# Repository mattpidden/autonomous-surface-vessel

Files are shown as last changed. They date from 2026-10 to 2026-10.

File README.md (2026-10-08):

# Autonomous Surface Vessel (ASV) Project
A 3D-printed autonomous sailing surface vessel designed for marine data collection and experimentation in autonomous navigation. 

## Capabilities
- Autonomous waypoint navigation
- Sail and rudder control
- GPS based localisation
- IMU-based heading and motion estimation
- Wind-aware sailing and route planning
- Marine environmental data collection
- Georeferenced data logging
- Computer vision for surface obstacle detection
- Remote telemetry and mission monitoring
- Autonomous mission planning

## Parts

### Compute & control (£135.00)
- [x] [Raspberry Pi 4 4GB](https://thepihut.com/products/raspberry-pi-4-model-b?variant=20064052740158) | ✓ £96.00 | 4GB is plenty for headless ROS 2 + light vision. 
- [x] [SanDisk High Endurance 64GB microSD](https://www.amazon.co.uk/SanDisk-Endurance-Monitoring-Dashcams-MicroSDXC/dp/B07P3D6Y5B) | £24 | Made for continuous writing, so it suits all-day data logging.
- [x] [Pico](https://thepihut.com/products/pimoroni-pico-lipo-2) | ✓ £15.00 | Pimoroni Pico LiPo 2 (RP2350). USB-C, Qw/ST and SP/CE connectors.

### Navigation & comms (£88.60)
- [x] [Waveshare A7670E Cat-1](https://thepihut.com/products/a7670e-lte-cat-1-hat-for-raspberry-pi-2g-gsm-gprs) | ✓ £28.80 | LTE telemetry.
- [x] [IoT data SIM](TODO) | ~£10 | Low-data telemetry SIM.
- [x] [Adafruit BNO055 9-DoF IMU](https://thepihut.com/products/adafruit-9-dof-absolute-orientation-imu-fusion-breakout-bno055-stemma-qt-qwiic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) | ✓ £28.80 | Does sensor fusion on the chip and gives roll, pitch and turn rate
- [x] [STEMMA QT Cable x2](https://thepihut.com/products/stemma-qt-qwiic-jst-sh-4-pin-cable-100mm-long) | ✓ £2.00
- [x] [USB-C to USB-A cables x2](https://thepihut.com/products/usb-a-to-usb-c-cable-1m) for LTE hat and for Pi to Pico | ✓ £7.00
- [x] [USB GPS](https://www.amazon.co.uk/Receiver-Navigation-Notebook-Interface-DC3-3-5V/dp/B0BRQGZ4QV) | £14

### Vision (£39.60)
- [x] [Raspberry Pi Camera Module 3 Wide](https://thepihut.com/products/raspberry-pi-camera-module-3) | ✓ £33.60 | CSI, 120° view, autofocus, HDR. Uses less power than USB and works with the ROS 2 `camera_ros` package.
- [ ] [Clear Protectino Dome for camera](TODO) | ~£6
- [x] [Longer camera cable](https://thepihut.com/products/flex-cable-for-raspberry-pi-camera-or-display-18-457mm)

### Environmental sensors (£123.20)
- [x] [Pressure Humidity Temperature PHT Sensor](https://thepihut.com/products/adafruit-ms8607-pressure-humidity-temperature-pht-sensor) | ✓ £14.40 | Air temp/humidity/pressure. Mount it on deck in a vented, shaded housing. Can be dasiy changed into IMU sensor.
- [x] [Wind Speed & Direction Transmiter](https://www.amazon.co.uk/Ultrasonic-Direction-Sensor-Anemometer-Measurable/dp/B0H3613T5G) | £83
- [x] [RS485 to TTL adapter](https://www.amazon.co.uk/Converter-Direction-Compatible-Industrial-Automation/dp/B0GVQRYVNQ) | £5.4 | Check it supports 3.3V logic.
- [x] [TTL to 8pin cable](https://thepihut.com/products/8-pin-jst-sh-cable-sp-ce?variant=53798448431489) | ✓ £1.80 | Pick the JST-SH to DuPont version.

### Actuation (£102.40)
- [x] [12V Worm Gear Motor with Encoders x2](https://www.amazon.co.uk/Torque-Geared-Reduction-Encoder-Self-locking/dp/B07DG9QYPY) 30RPM for rudder and 10RPM for wing sail | £27 (£13.8 each)
- [x] [Motor driver](https://thepihut.com/products/dc-motor-driver-module-for-raspberry-pi-pico) | ✓ £14.40
- [x] [Power adapter for driver](https://thepihut.com/products/dc-dc-power-module-25w) £8.20
- [x] [Thruster motor](https://www.amazon.co.uk/ApisQueen-U2-Bi-Directional-ESC-Screw-Propellers/dp/B0C74CMXR9) | £62

### Power (£92.00)
- [x] [12V 12Ah LiFePO4 battery](https://www.amazon.co.uk/DCHOUSE-Trolling-Household-Appliances-Emergency/dp/B0CNP6Q28P) | £41.5 | 
- [x] [Battery Charger](https://www.amazon.co.uk/ECO-WORTHY-Lithium-LiFePO4-Automatic-Maintainer-black/dp/B0DGL4HKS6?th=1) | 36gbp
- [x] [Step down 12V to 5V for Pi](https://www.amazon.co.uk/DC-DC-Step-Converter-Type-C-Interface-as-shown-detailed-picture/dp/B0H7S63FXC) | £9
- [x] [On/off switch](https://www.amazon.co.uk/Joinfworld-Waterproof-Toggle-Mounting-Automotive/dp/B0G3982R8M) 10gbp

### Structure (£18.00)
- [ ] [Keel weights (lead)](https://www.claygame.co.uk/lead-shot-samples-pd378) | £18 for 2kg
- [ ] [2KG ABA Filament](https://uk.store.bambulab.com/products/abs-filament?id=41905581916220) £30

## Power budget (average draw at the battery)
| Load | Watts |
|---|---|
| Pi 4 headless + ROS 2 (after ~90% efficient 5V converter) | 3.5 |
| Camera + low-rate obstacle detection (runs part of the time) | 0.8 |
| Ultrasonic wind sensor (12V) | 0.6 |
| LTE Cat-1 telemetry | 0.5 |
| Rudder worm gear (self-locking, moves often) | 0.5 |
| Pico LiPo 2 | 0.15 |
| USB GPS | 0.15 |
| Sail worm gear (self-locking, moves rarely) | 0.15 |
| IMU, PHT sensor, motor driver idle | 0.1 |
| **Total** | **~6.5 W, ~155 Wh/day** |

A 12Ah LiFePO4 holds ~154Wh (~138Wh usable), which gives **~21h with no thruster use**. The thruster draws tens of watts, so every hour it runs costs several hours of endurance. To reach 24h, run the camera only near obstacles or in harbours, turn off Wi-Fi/Bluetooth/HDMI, or fit a larger battery if the weight budget allows. The wind sensor figure is typical for ultrasonic sensors, so check its datasheet.

## Software stack
**Raspberry Pi 4** (Ubuntu Server 24.04, headless, ROS 2 Jazzy)
- Localisation: `robot_localization` EKF fusing USB GPS (`nmea_navsat_driver`) with IMU heading from the Pico
- Planning: wind-aware sailing planner that turns waypoints into a course to steer and decides when to tack
- Vision: `camera_ros` + lightweight obstacle detection at a low frame rate
- Telemetry over LTE, and data logging with `rosbag2`

**Pimoroni Pico LiPo 2** (micro-ROS over USB serial, or a simple serial bridge if micro-ROS doesn't support the RP2350 yet)
- Reads the IMU and PHT sensor over I2C (Qw/ST) and the wind sensor over RS485/Modbus (SP/CE)
- Drives the rudder and sail worm gears to position using their encoders. Both are centred by hand at startup.
- Steers to the course from the Pi and trims the sail to the wind
- Sends the thruster ESC its PWM signal

## Assembly
- 3D print the hull in 3x1 sections with conectors
- Use acertone to bond together, then coat in epoxy
- Same for keel, which bolts into hull from inside
- Same for wing sail
- Use heat sets into the hull for modular plate system
- Design modular plate system to house all electronics
- Grease stuffed tubes for rudder and sail shafts
- Pole bolted to transom for Wind sensor, celluar arial, and IMU/PHT mounting 
- Lid with rubber seal and bolted down?
- On/off switch mounted on deck aft of sail

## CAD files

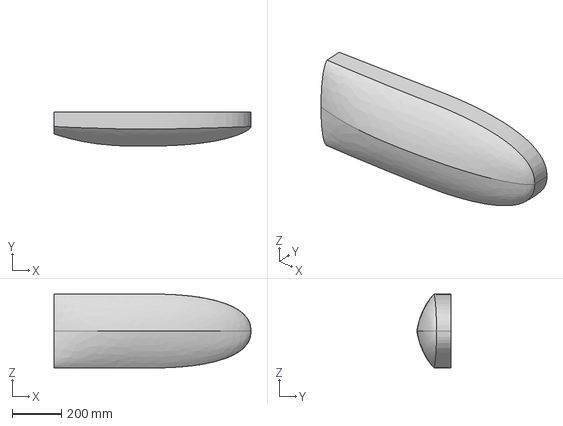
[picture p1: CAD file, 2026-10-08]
cad/scowhull.step
800.0 x 140.0 x 300.1 mm

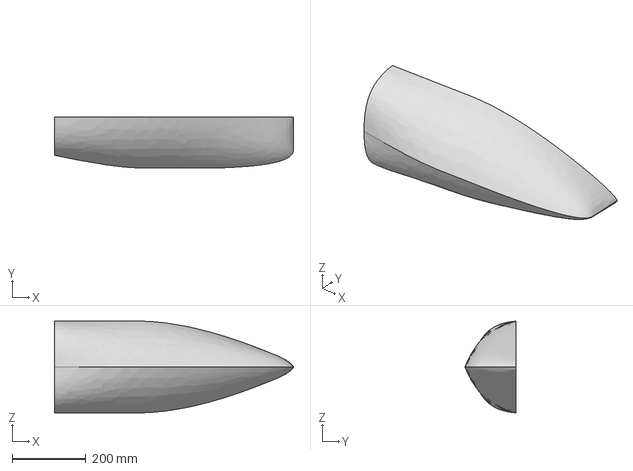
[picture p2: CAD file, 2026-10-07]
cad/hull.step
650.0 x 140.0 x 250.0 mm

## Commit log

2026-10-05 first version of hull complete
    [hull.step]
2026-10-05 updateds hull length to width ratio
    [hull.step]
2026-10-05 hullv3 with adjusted dimensions and lines
2026-10-07 updated parts list and ordered first batch
    [hull.step]
2026-10-08 added alternative scow bow design hull and assembly notes
    [scowhull.step]
2026-10-13 added keel and updated scow hull to be deeper
2026-10-16 added keel joint
2026-10-16 added thruster mount
2026-10-16 added rudder, motor mount, battery mount, and some parts to list
2026-10-17 added docs for pi and pico setup, added test code for pico sensor readings and verified sensors good
2026-11-10 updated cad to include hull top, and boses in bow and dowel holes
2026-11-11 added videos and cad updates
2026-11-12 latest cad and updated readme
2026-11-12 new step for midships print and updated readme
